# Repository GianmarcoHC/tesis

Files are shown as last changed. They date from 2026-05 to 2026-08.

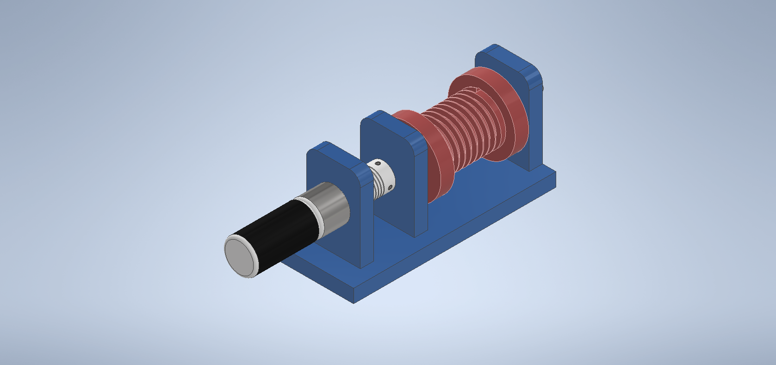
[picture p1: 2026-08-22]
cad/CAD/Ensamblaje2.png

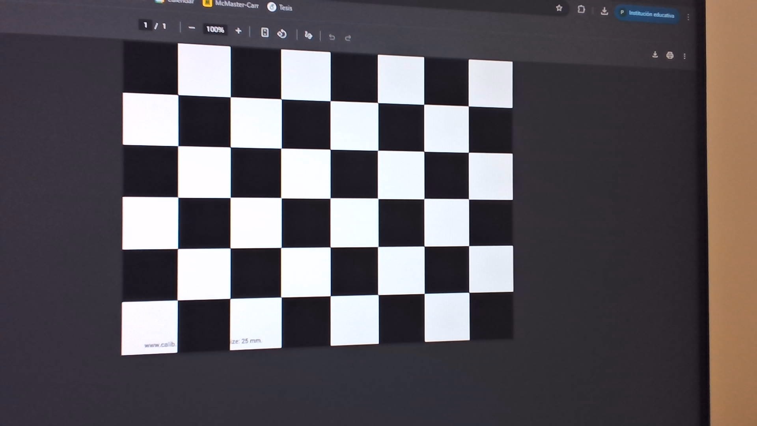
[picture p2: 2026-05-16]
camara/calib/5.jpg

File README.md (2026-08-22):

# Cable-Driven Parallel Robot (CDPR)

> Sistema de posicionamiento XYZ suspendido por cables para monitoreo y localización mediante visión artificial — Tesis UTEC

---

## ¿Qué es este proyecto?

Un **Cable-Driven Parallel Robot (CDPR)** es un robot paralelo donde los eslabones rígidos son reemplazados por cables. Este proyecto implementa un sistema de posicionamiento 3D que combina control embebido en ESP32 con visión artificial para estimar la posición y orientación del efector final en tiempo real.

El repositorio incluye tanto la implementación embebida (firmware, visión) como el modelado y análisis en MATLAB/Simulink utilizados durante el diseño y la sintonización del sistema de control.

---

## Estructura del repositorio

```
tesis/
├── cad/                    # Modelos 3D del prototipo
├── camara/                 # Visión artificial — calibración, AprilTags y pose
├── control/                # Firmware ESP32 — motores, encoders y cinemática
└── matlab/                 # Modelado, control y simulación en MATLAB/Simulink
    ├── implementacion/     # Identificación del motor, sintonización PID (AG)
    │                       # y control cinemático (cámara → Simulink → ESP32)
    └── simulacion/         # Simulación completa con Simscape Multibody
```

---

## Módulos

### `cad/`

Modelos 3D del sistema mecánico del prototipo.

**Formato:** Autodesk Inventor / STL

---

### `camara/`

Pipeline de visión artificial para localización del robot.

| Componente | Descripción |
|---|---|
| Calibración | Estimación de parámetros intrínsecos de cámara |
| AprilTags | Detección de marcadores fiduciales |
| Pose | Estimación de posición y orientación 6DOF |
| Scripts | Herramientas de prueba y validación |

**Dependencias:**
- Python 3.x
- OpenCV
- NumPy
- AprilTag

---

### `control/`

Firmware embebido para el **ESP32** desarrollado con PlatformIO + ESP-IDF.

| Componente | Descripción |
|---|---|
| Motores | Control de velocidad y dirección |
| Encoders | Lectura de posición angular |
| Cinemática | Cálculo de longitudes de cable |
| Trayectoria | Planificación y seguimiento de trayectorias |
| Comunicación | Interfaz serial con PC |

**Stack:**
- ESP32 + FreeRTOS
- ESP-IDF
- PlatformIO

> La lógica principal vive en `main/`. El sistema corre tareas concurrentes con FreeRTOS.

---

### `matlab/`

Modelado, sintonización y simulación del sistema de control, dividido en dos subcarpetas según su propósito.

#### `matlab/implementacion/`

Scripts y modelo empleados para llevar el controlador desde el diseño hasta el prototipo físico: identifican la planta real, optimizan las ganancias del PID y ejecutan el lazo de control cinemático que corre en conjunto con el prototipo.

| Componente | Descripción |
|---|---|
| Identificación del motor | Estimación de los parámetros del modelo de primer orden del motor DC (ganancia K y constante de tiempo τ) a partir de datos experimentales |
| Sintonización PID (AG) | Optimización de las ganancias Kp, Ki, Kd del lazo interno mediante algoritmo genético |
| Control cinemático (Simulink) | Modelo que recibe la posición y orientación estimadas por la cámara, calcula el error respecto a la trayectoria de referencia y genera las señales de control enviadas al ESP32 |

**Stack:** MATLAB, Simulink

#### `matlab/simulacion/`

Modelo de simulación del sistema completo, independiente del hardware, usado para validar el comportamiento dinámico del efector antes de la implementación.

| Componente | Descripción |
|---|---|
| Modelo multicuerpo | Simulación de la dinámica del efector final suspendido por cables, desarrollada con Simscape Multibody |

**Stack:** MATLAB, Simulink, Simscape Multibody

---

## Autores

**Gianmarco Humpiri Coila** — UTEC
**Piero Reyes Velarde** — UTEC

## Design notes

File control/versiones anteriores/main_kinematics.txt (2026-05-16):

#include <stdio.h>
#include "EncoderClass.h"
#include "MotorClass.h"
#include "PIDClass.h"
#include "uart_manager.h"
#include "freertos/FreeRTOS.h"
#include "freertos/task.h"
#include "esp_log.h"

// === Parámetros generales ===
const float Ts = 0.02f;  // periodo de muestreo (s)

// === UART I/O ===
static int16_t inputs[4];   // desde MATLAB → ESP32 (setpoints)
static int16_t outputs[4];  // desde ESP32 → MATLAB (posiciones)

// === PID (idéntico para todos los motores) ===
const float Kp = 1.00f;
const float Ki = 0.00f;
const float Kd = 0.00f;

// === Objetos globales ===
// Encoders
EncoderClass encoder1(GPIO_NUM_15, GPIO_NUM_2, PCNT_UNIT_0);
EncoderClass encoder2(GPIO_NUM_35, GPIO_NUM_34, PCNT_UNIT_1);
EncoderClass encoder3(GPIO_NUM_21, GPIO_NUM_22, PCNT_UNIT_2);
EncoderClass encoder4(GPIO_NUM_18,  GPIO_NUM_19,  PCNT_UNIT_3);

// Motores
MotorClass Motor1(GPIO_NUM_32, GPIO_NUM_33, MCPWM_UNIT_0, MCPWM_TIMER_0, MCPWM_OPR_A);
MotorClass Motor2(GPIO_NUM_25, GPIO_NUM_26, MCPWM_UNIT_0, MCPWM_TIMER_1, MCPWM_OPR_A);
MotorClass Motor3(GPIO_NUM_27, GPIO_NUM_14, MCPWM_UNIT_1, MCPWM_TIMER_0, MCPWM_OPR_A);
MotorClass Motor4(GPIO_NUM_5,  GPIO_NUM_4,  MCPWM_UNIT_1, MCPWM_TIMER_1, MCPWM_OPR_A);

// PID
PIDClass pid1(Kp, Ki, Kd, Ts);
PIDClass pid2(Kp, Ki, Kd, Ts);
PIDClass pid3(Kp, Ki, Kd, Ts);
PIDClass pid4(Kp, Ki, Kd, Ts);

// === Estructura de control ===
struct MotorControl {
    EncoderClass *encoder;
    MotorClass *motor;
    PIDClass *pid;
    const char *name;
    int index;   // índice para inputs/outputs
};

// === Tarea de control PID ===
void control_motor_task(void *pvParameters)
{
    MotorControl *mc = (MotorControl *)pvParameters;
    TickType_t last_wake_time = xTaskGetTickCount();

    while (true)
    {
        // Setpoint desde MATLAB (input)
        float setpoint = (float)inputs[mc->index];
        float position = mc->encoder->read_degrees();

        // Guardar posición actual en outputs → MATLAB
        outputs[mc->index] = (int16_t)position;

        // Calcular control PID
        float control = mc->pid->compute(setpoint, position);

        // Saturación de seguridad
        if (control > 100.0f) control = 100.0f;
        if (control < -100.0f) control = -100.0f;

        mc->motor->setPWM(control);

        // Log de depuración
        // ESP_LOGI(mc->name, "Set: %.1f°  Pos: %.2f°  PWM: %.2f", setpoint, position, control);

        vTaskDelayUntil(&last_wake_time, pdMS_TO_TICKS((uint32_t)(Ts * 1000.0f)));
    }
}

// === Configuración principal ===
extern "C" void app_main(void)
{
    gpio_reset_pin(GPIO_NUM_4);
    gpio_reset_pin(GPIO_NUM_14);

    // Iniciar UART (comunicación con MATLAB)
    start_uart_task(inputs, outputs);

    // Inicializar motores
    Motor1.MotorInitialize();
    Motor2.MotorInitialize();
    Motor3.MotorInitialize();
    Motor4.MotorInitialize();

    // Inicializar encoders
    encoder1.begin();
    encoder2.begin();
    encoder3.begin();
    encoder4.begin();

    vTaskDelay(pdMS_TO_TICKS(2000));

    // Crear estructuras de control
    static MotorControl mc1 = { &encoder1, &Motor1, &pid1, "MOTOR1", 0 };
    static MotorControl mc2 = { &encoder2, &Motor2, &pid2, "MOTOR2", 1 };
    static MotorControl mc3 = { &encoder3, &Motor3, &pid3, "MOTOR3", 2 };
    static MotorControl mc4 = { &encoder4, &Motor4, &pid4, "MOTOR4", 3 };

    // Crear tareas de control en core 1
    xTaskCreatePinnedToCore(control_motor_task, "control_motor1", 4096, &mc1, 5, NULL, 1);
    xTaskCreatePinnedToCore(control_motor_task, "control_motor2", 4096, &mc2, 5, NULL, 1);
    xTaskCreatePinnedToCore(control_motor_task, "control_motor3", 4096, &mc3, 5, NULL, 1);
    xTaskCreatePinnedToCore(control_motor_task, "control_motor4", 4096, &mc4, 5, NULL, 1);

    ESP_LOGI("MAIN", "Control PID + UART iniciado correctamente.");
}

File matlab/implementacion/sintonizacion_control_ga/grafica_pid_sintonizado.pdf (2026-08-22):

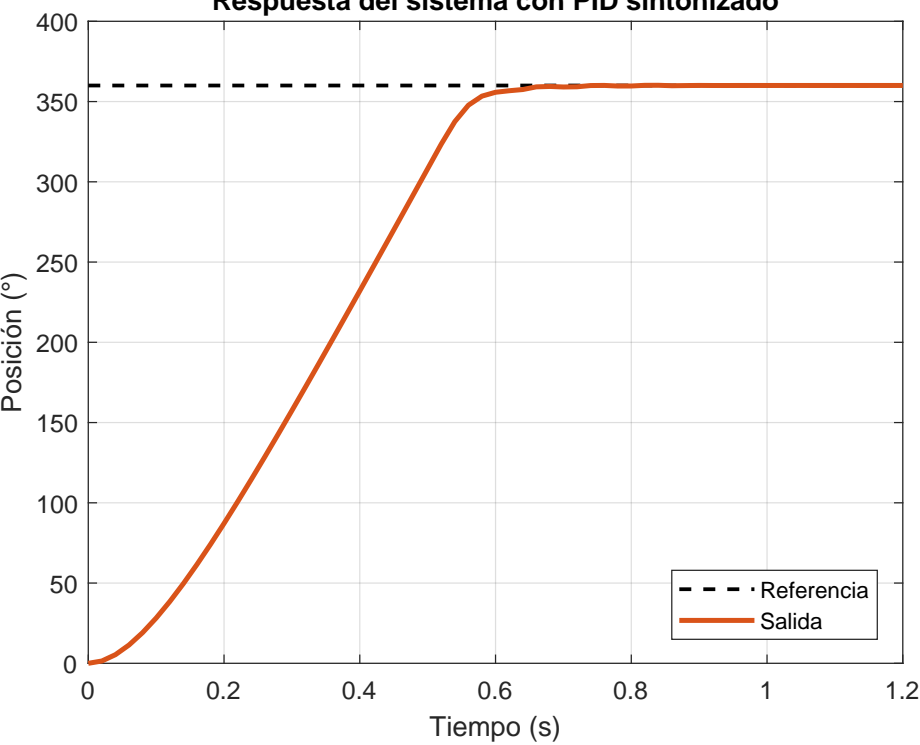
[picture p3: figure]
Tiempo (s); Posición (°); Referencia Salida

Respuesta del sistema con PID sintonizado

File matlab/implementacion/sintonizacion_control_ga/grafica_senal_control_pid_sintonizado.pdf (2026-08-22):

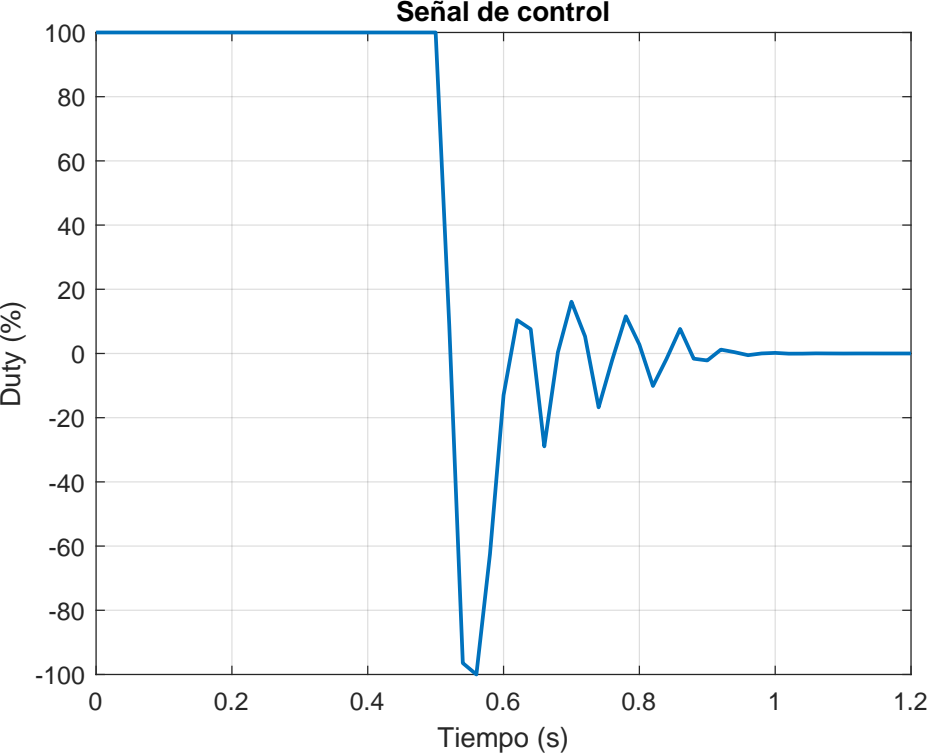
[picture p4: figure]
Tiempo (s); Duty (%); Señal de control

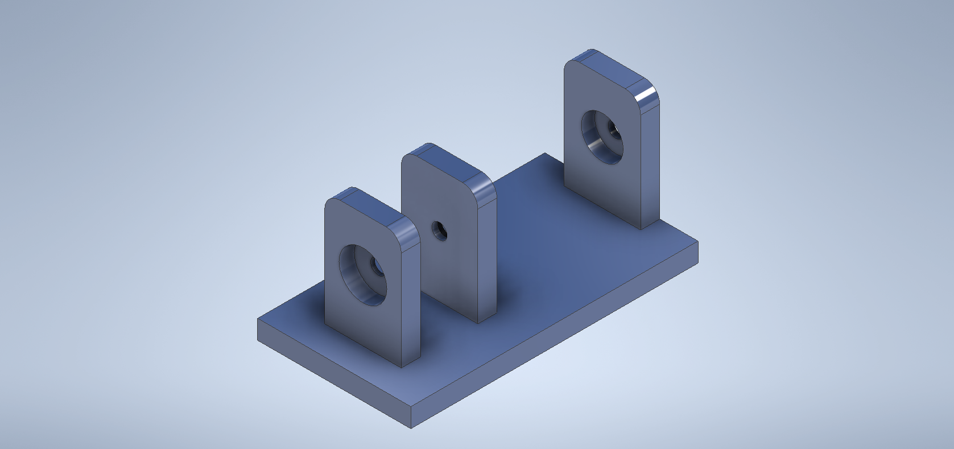
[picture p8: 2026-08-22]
cad/CAD/soporte_inferior.png

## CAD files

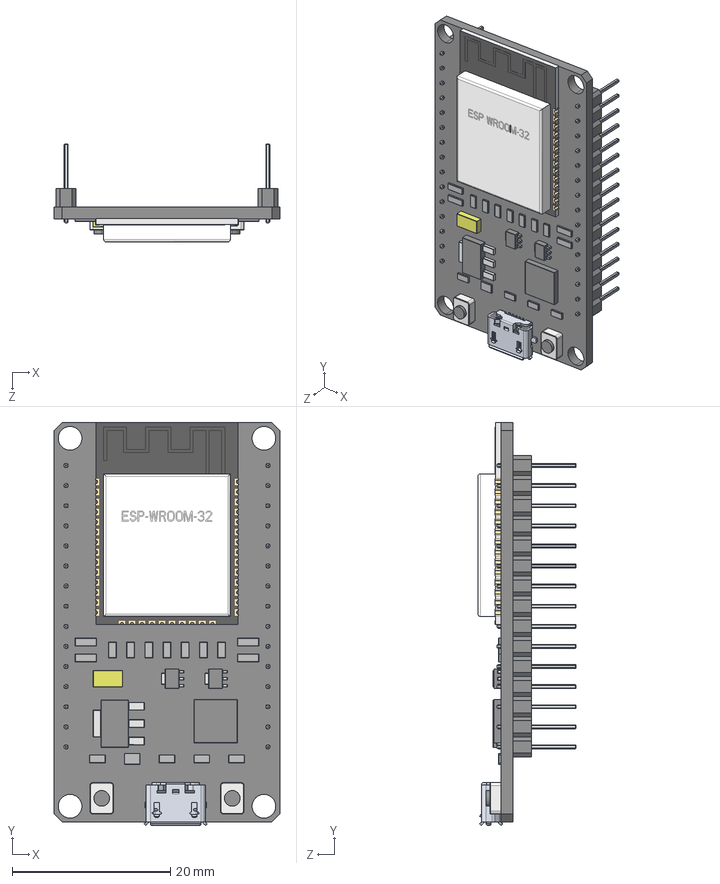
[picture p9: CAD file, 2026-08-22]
cad/CAD/Electronicos/esp-32-1.snapshot.6/ESP-32_v1.STEP
28.5 x 50.9 x 12.4 mm
6.ESP-32_Predeterminado
micro_usb_47346-0001
KiCAD-ESP-WROOM-32_Predeterminado

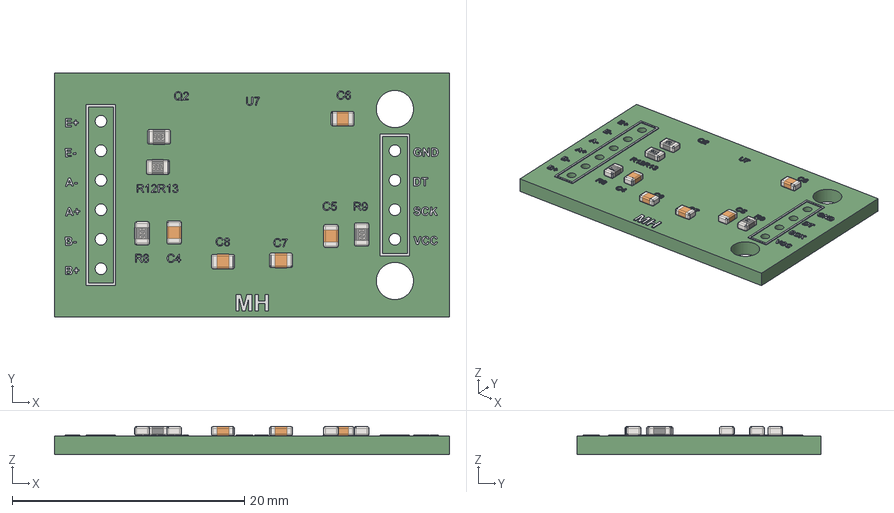
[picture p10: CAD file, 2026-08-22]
cad/CAD/Electronicos/hx711-breakout-board-1.snapshot.2/HX711 Breakout v8 ohne Pinheader.step
34.0 x 21.0 x 2.45 mm
Valor predeterminado
Valor predeterminado_1
Valor predeterminado_2 x 2
base_HX711-1
pino_HX711-1
pino_HX711-2
pino_HX711-3
pino_HX711-4
pino_HX711-5
pino_HX711-6
pino_HX711-7
pino_HX711-8
pino_HX711-9
pino_HX711-10
pino_HX711-11
pino_HX711-12
pino_HX711-13
pino_HX711-14
pino_HX711-15
pino_HX711-16
TRANSISTOR_SOT23-1
PINO_SOT23-1
PINO_SOT23-2
PINO_SOT23-3
Valor predeterminado_5 x 5

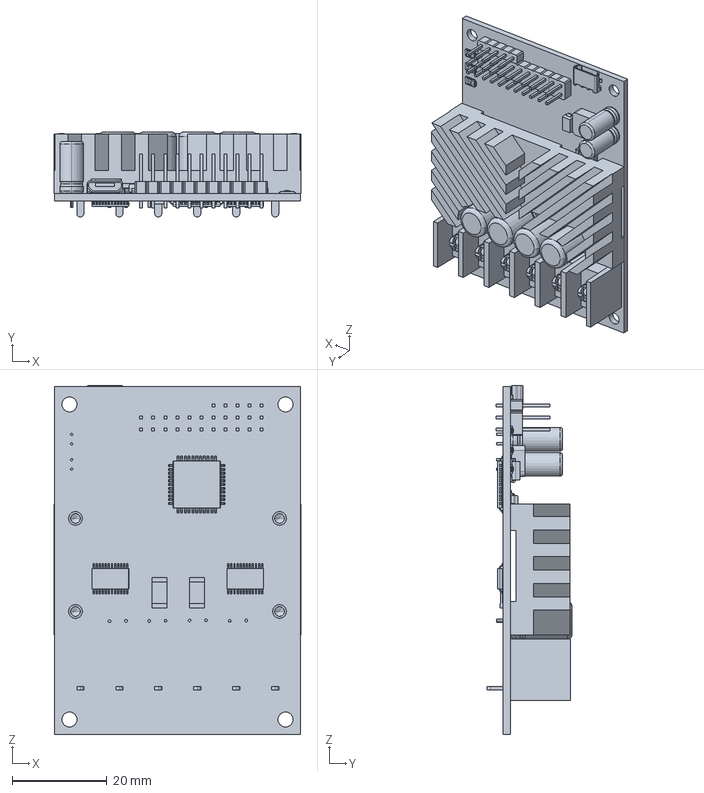
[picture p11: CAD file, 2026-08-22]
cad/CAD/Electronicos/MC15A_V5/MC15A_V5_1779569544.214.step
52.3 x 18.0 x 73.9 mm
eMachineShop.1.1
eMachineShop.1.2
eMachineShop.1.3
eMachineShop.1.4
eMachineShop.1.5
eMachineShop.1.6
eMachineShop.1.7
eMachineShop.1.8
eMachineShop.1.9
eMachineShop.1.10
eMachineShop.1.11
eMachineShop.1.12
eMachineShop.1.13
eMachineShop.1.14
eMachineShop.1.15
eMachineShop.1.16
eMachineShop.1.17
eMachineShop.1.18
eMachineShop.1.19
eMachineShop.1.20
eMachineShop.1.21
eMachineShop.1.22
eMachineShop.2.1
eMachineShop.2.2
eMachineShop.2.3
eMachineShop.2.4
eMachineShop.2.5
eMachineShop.2.6
eMachineShop.2.7
eMachineShop.2.8
eMachineShop.2.9
eMachineShop.2.10
eMachineShop.2.11
eMachineShop.2.12
eMachineShop.2.13
eMachineShop.2.14
eMachineShop.2.15
eMachineShop.2.16
eMachineShop.2.17
eMachineShop.2.18
eMachineShop.2.19
eMachineShop.2.20
eMachineShop.2.21
eMachineShop.2.22
eMachineShop.2.23
eMachineShop.2.24
eMachineShop.2.25
eMachineShop.2.26
eMachineShop.2.27
eMachineShop.2.28
eMachineShop.2.29
eMachineShop.2.30
eMachineShop.2.31
eMachineShop.2.32
eMachineShop.2.33
eMachineShop.2.34
eMachineShop.2.35
eMachineShop.2.36
eMachineShop.2.37
eMachineShop.2.38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

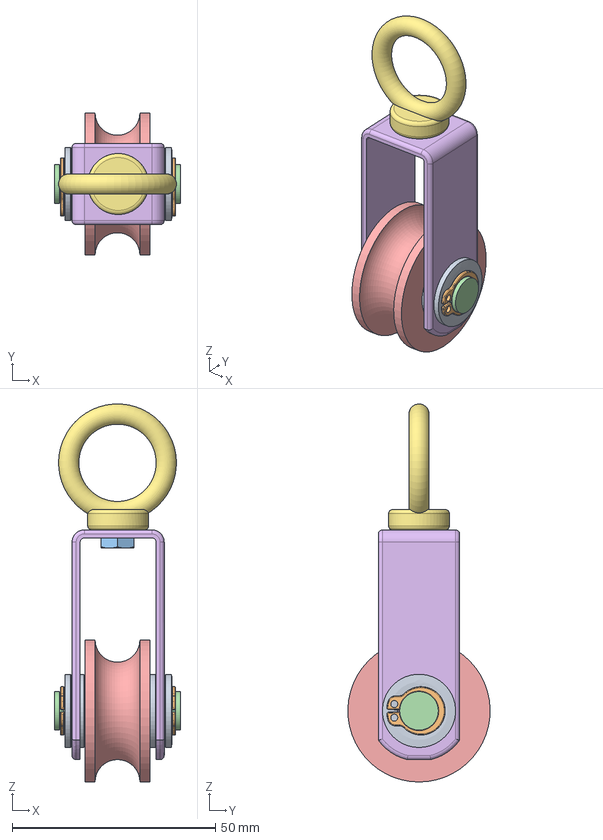
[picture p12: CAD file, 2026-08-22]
cad/CAD/Polea/suspended-pulley-1.snapshot.1/carrucola sospesa v3.step
31.0 x 35.0 x 93.0 mm
98689A117_General Purpose 18-8 Stainless Steel Washer x 4
90967A160_External Retaining Ring x 2
91287A081_18-8 Stainless Steel Hex Head Screw

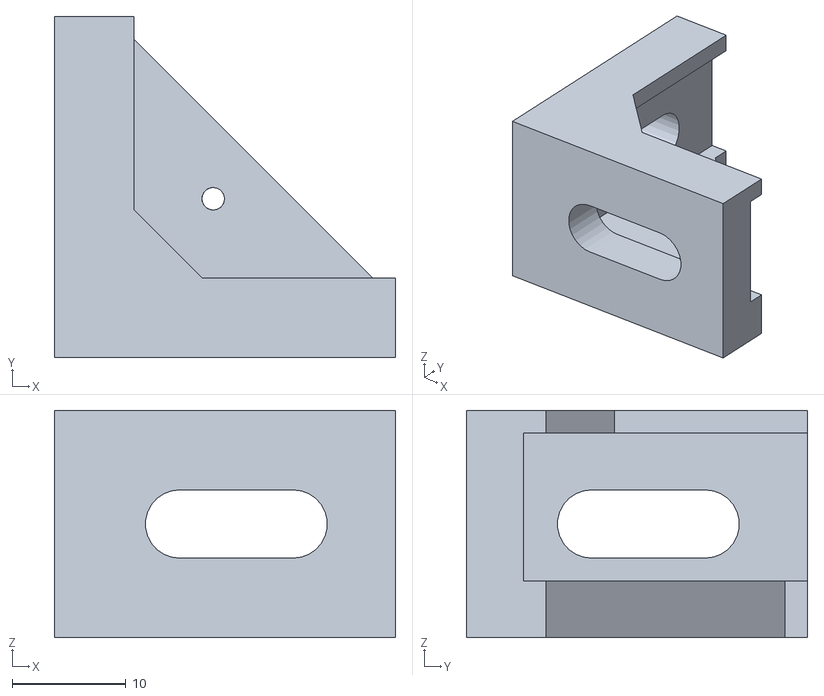
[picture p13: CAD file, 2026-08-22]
cad/Impresion 3D/soporte_gancho.stl
30.0 x 30.0 x 20.0

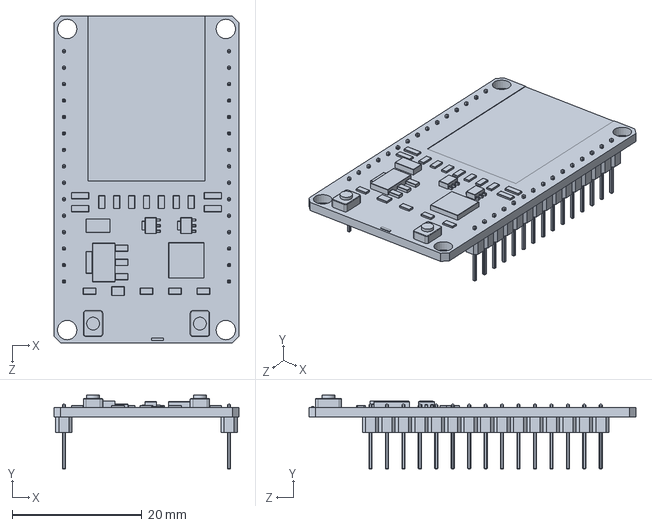
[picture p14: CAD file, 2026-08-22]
cad/CAD/Electronicos/esp-32-1.snapshot.6/6.ESP-32.SLDPRT
28.5 x 11.4 x 50.5 mm

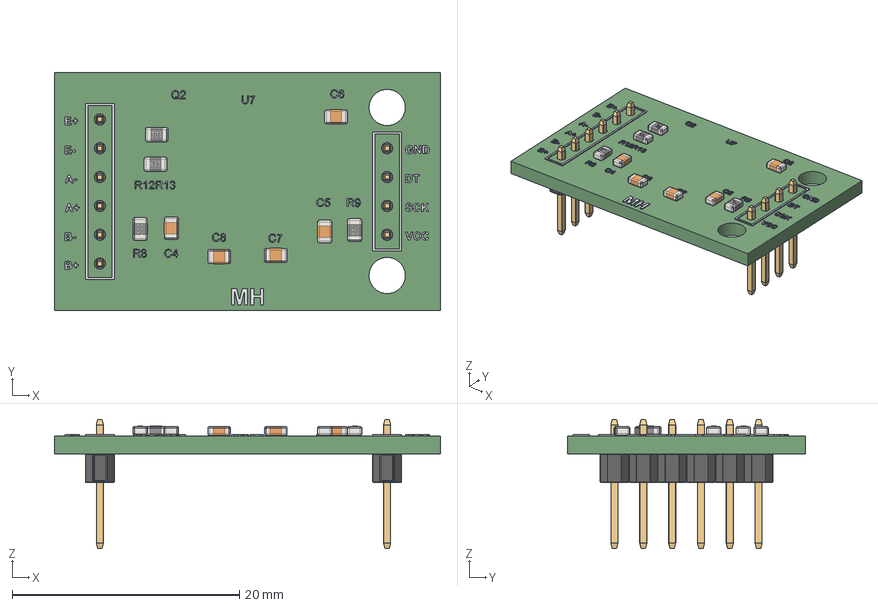
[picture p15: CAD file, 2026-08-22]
cad/CAD/Electronicos/hx711-breakout-board-1.snapshot.2/HX711 Breakout v7.step
34.0 x 21.0 x 11.4 mm
Valor predeterminado
Valor predeterminado_1
Valor predeterminado_2 x 2
base_HX711-1
pino_HX711-1
pino_HX711-2
pino_HX711-3
pino_HX711-4
pino_HX711-5
pino_HX711-6
pino_HX711-7
pino_HX711-8
pino_HX711-9
pino_HX711-10
pino_HX711-11
pino_HX711-12
pino_HX711-13
pino_HX711-14
pino_HX711-15
pino_HX711-16
TRANSISTOR_SOT23-1
PINO_SOT23-1
PINO_SOT23-2
PINO_SOT23-3
Valor predeterminado_5 x 5
Male Pin Header x 4
Male Pin Header_1 x 6

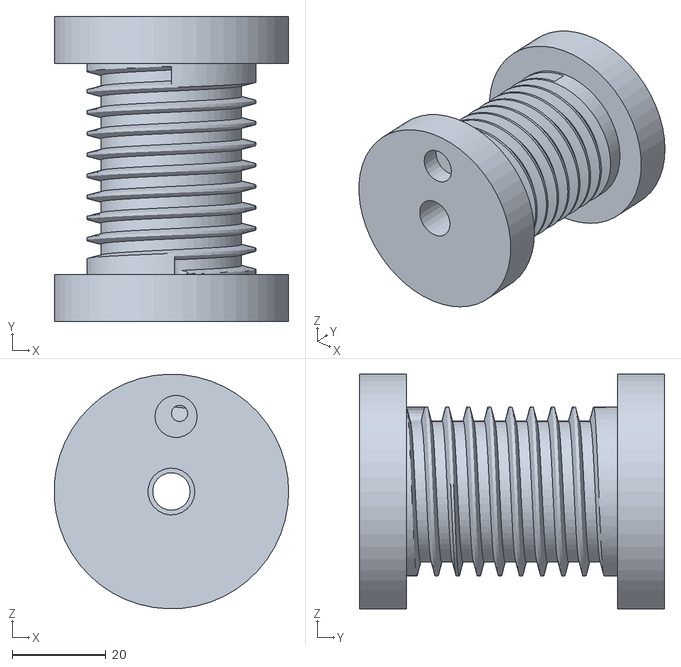
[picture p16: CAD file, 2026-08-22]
cad/Impresion 3D/carrete.stl
50.0 x 65.0 x 50.0

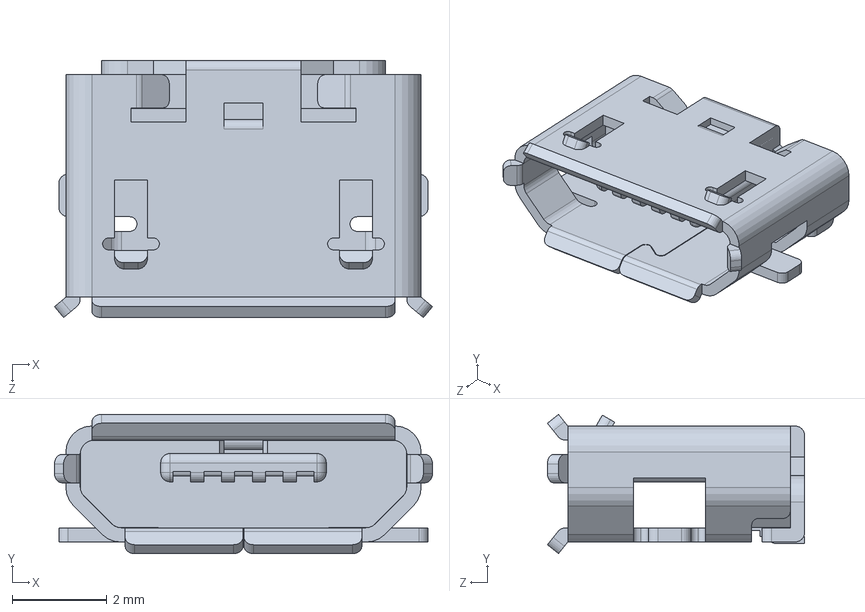
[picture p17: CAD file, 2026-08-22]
cad/CAD/Electronicos/esp-32-1.snapshot.6/micro_usb_47346-0001.SLDPRT
7.98 x 2.94 x 5.43 mm

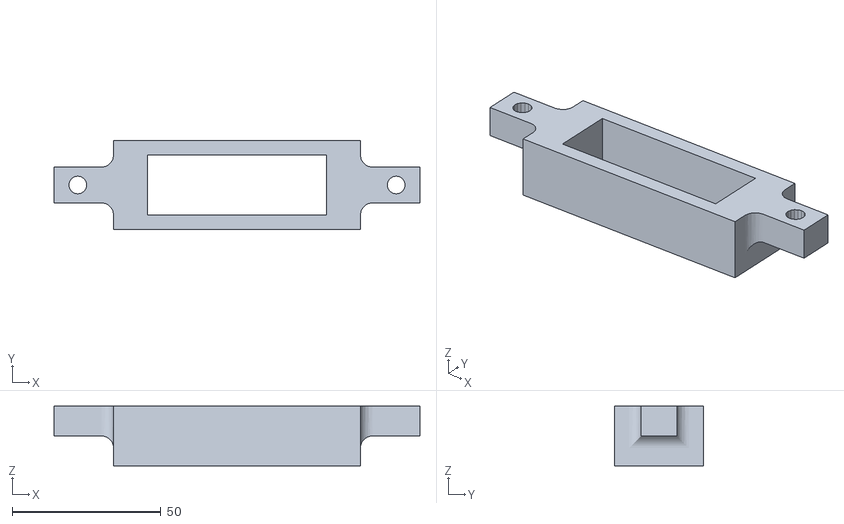
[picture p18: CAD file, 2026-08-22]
cad/Impresion 3D/carcasa_webcam.stl
123.0 x 30.0 x 20.0

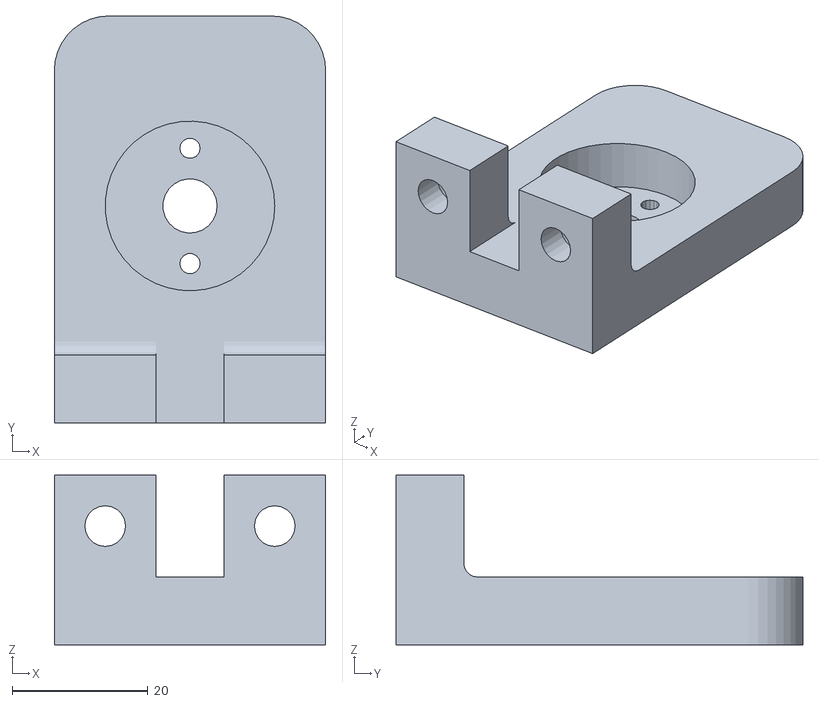
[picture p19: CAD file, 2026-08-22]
cad/Impresion 3D/sujeción motor-acople.stl
40.0 x 60.0 x 25.0

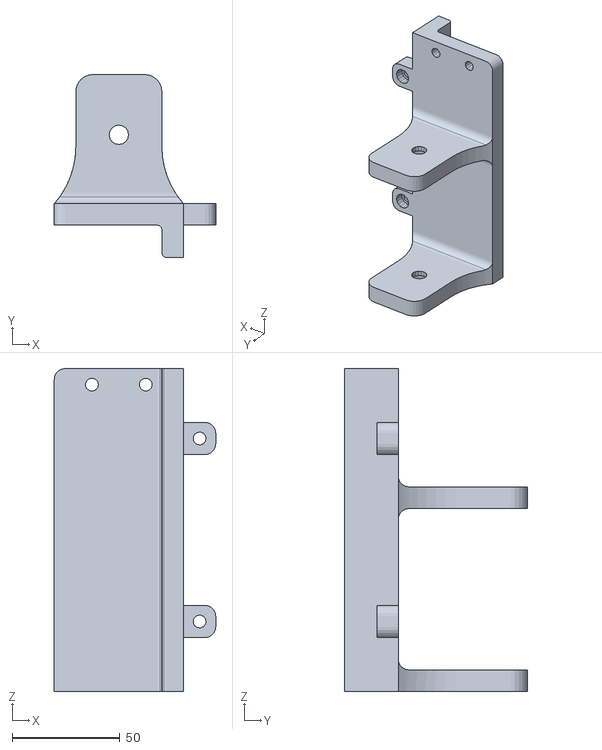
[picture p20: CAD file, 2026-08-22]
cad/Impresion 3D/soporte_inferior.stl
75.0 x 85.0 x 150.0

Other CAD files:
cad/CAD/Ensamblaje1.dwg
cad/CAD/Electronicos/MC15A_V5/MC15A_V5.IGS
cad/CAD/Electronicos/esp-32-1.snapshot.6/ESP-WROOM-32.sldprt
cad/CAD/Base.ipt
cad/CAD/BaseMotor.ipt
cad/CAD/Base_motor.ipt
cad/CAD/Brida.ipt
cad/CAD/Brida1.ipt
cad/CAD/Electronicos/MC15A_V5/MC15A_V5/311-1366-2-ND.ipt
cad/CAD/Electronicos/MC15A_V5/MC15A_V5/609-4618-1-ND.ipt
cad/CAD/Electronicos/MC15A_V5/MC15A_V5/620-1319-1-ND.ipt
cad/CAD/Electronicos/MC15A_V5/MC15A_V5/ATXMEGA32A4U-AU-ND.ipt
cad/CAD/Electronicos/MC15A_V5/MC15A_V5/CRF2512-FV-R001ELFCT-ND.ipt
cad/CAD/Electronicos/MC15A_V5/MC15A_V5/ED2949-ND.ipt
cad/CAD/Electronicos/MC15A_V5/MC15A_V5/LM22676MRE-5.0_NOPBTR-ND.ipt
cad/CAD/Electronicos/MC15A_V5/MC15A_V5/MC15A_V5.iam
cad/CAD/Electronicos/MC15A_V5/MC15A_V5/MC30A_HeatSink_V5.ipt
cad/CAD/Electronicos/MC15A_V5/MC15A_V5/MCV30A-PCB.ipt
cad/CAD/Electronicos/MC15A_V5/MC15A_V5/OldVersions/MC15A_V5.0001.iam
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

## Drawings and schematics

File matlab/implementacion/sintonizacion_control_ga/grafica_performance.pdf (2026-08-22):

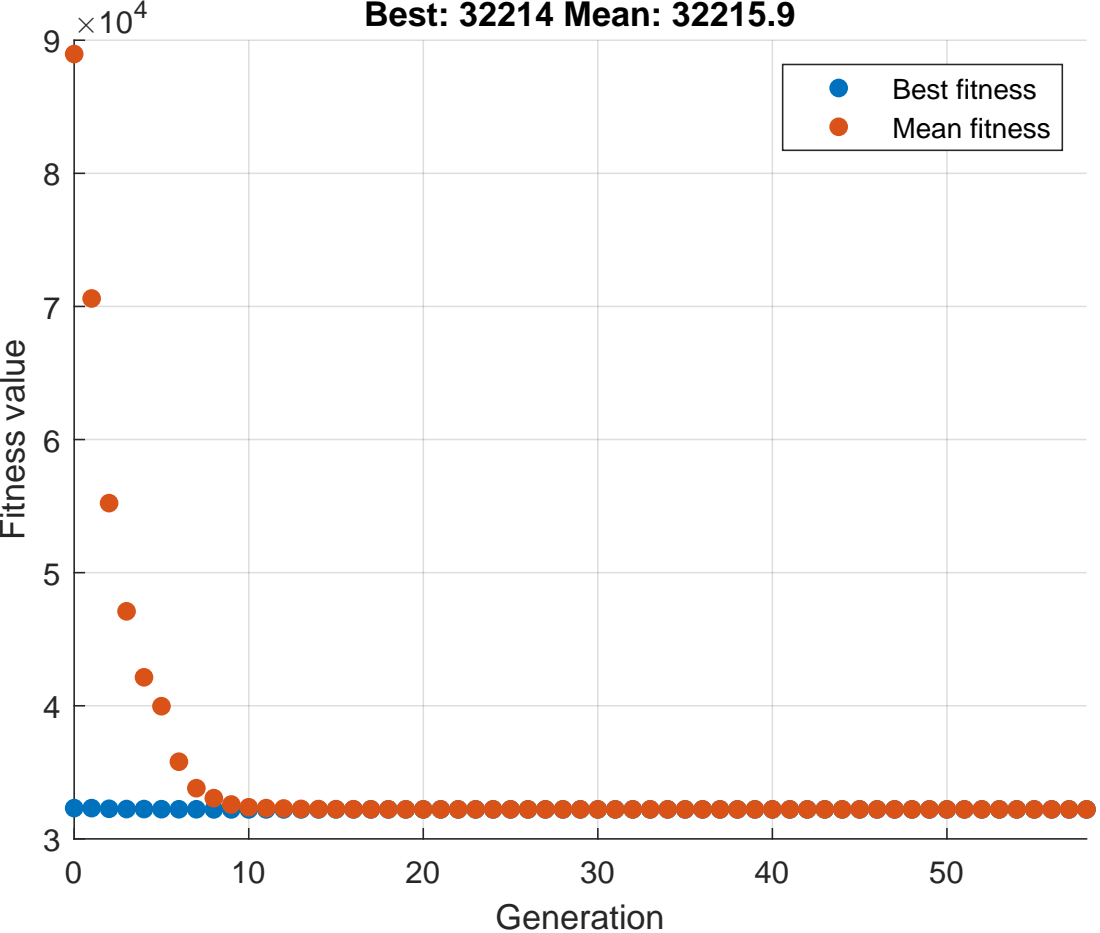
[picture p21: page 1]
Generation; Fitness value; Best: 32214 Mean: 32215.9; Best fitness Mean fitness

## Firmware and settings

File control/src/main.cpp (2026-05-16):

#include <stdio.h>
#include <string.h>

#include "freertos/FreeRTOS.h"
#include "freertos/Task.h"

#include "esp_now.h"
#include "esp_wifi.h"
#include "esp_netif.h"
#include "esp_mac.h"
#include "esp_event.h"
#include "nvs_flash.h"
#include "esp_log.h"

// ==== CONTROL (tus librerías) ====
#include "EncoderClass.h"
#include "MotorClass.h"
#include "PIDClass.h"
#include "uart_manager.h"

// ===============================
// ESP-NOW PACKET STRUCT
// ===============================
typedef struct __attribute__((packed)) {
    int16_t roll_x100;   // roll * 100
    int16_t pitch_x100;  // pitch * 100
} imu_packet_t;

static const char *TAG = "CONTROL_NODE";

// ===============================
// UART I/O
// ===============================
static int16_t inputs[4];   // MATLAB → ESP32
static int16_t outputs[4];  // ESP32 → MATLAB

// ===============================
// CONTROL DEFINITIONS
// ===============================
const float Ts = 0.02f;
static float pos_ref[4] = {0,0,0,0};

const float Kp = 1.0f;
const float Ki = 0.0f;
const float Kd = 0.0f;

// Encoders
EncoderClass encoder1(GPIO_NUM_15, GPIO_NUM_2, PCNT_UNIT_0);
EncoderClass encoder2(GPIO_NUM_35, GPIO_NUM_34, PCNT_UNIT_1);
EncoderClass encoder3(GPIO_NUM_21, GPIO_NUM_22, PCNT_UNIT_2);
EncoderClass encoder4(GPIO_NUM_18, GPIO_NUM_19, PCNT_UNIT_3);

// Motores
MotorClass Motor1(GPIO_NUM_32, GPIO_NUM_33, MCPWM_UNIT_0, MCPWM_TIMER_0, MCPWM_OPR_A);
MotorClass Motor2(GPIO_NUM_25, GPIO_NUM_26, MCPWM_UNIT_0, MCPWM_TIMER_1, MCPWM_OPR_A);
MotorClass Motor3(GPIO_NUM_27, GPIO_NUM_14, MCPWM_UNIT_1, MCPWM_TIMER_0, MCPWM_OPR_A);
MotorClass Motor4(GPIO_NUM_5,  GPIO_NUM_4,  MCPWM_UNIT_1, MCPWM_TIMER_1, MCPWM_OPR_A);

// PID
PIDClass pid1(Kp, Ki, Kd, Ts);
PIDClass pid2(Kp, Ki, Kd, Ts);
PIDClass pid3(Kp, Ki, Kd, Ts);
PIDClass pid4(Kp, Ki, Kd, Ts);

// ===============================
// ESTRUCTURA PARA EL CONTROL
// ===============================
struct MotorControl {
    EncoderClass *encoder;
    MotorClass *motor;
    PIDClass *pid;
    int index;
    const char *name;
};

// ===============================
// ESP-NOW: CALLBACK DE RECEPCIÓN
// ===============================
void espnow_recv_cb(const esp_now_recv_info_t *info, const uint8_t *data, int len)
{
    if (len == sizeof(imu_packet_t)) {
        const imu_packet_t *pkt = (const imu_packet_t*) data;

        outputs[0] = pkt->roll_x100;   // roll *100
        outputs[1] = pkt->pitch_x100;  // pitch*100
        outputs[2] = 0;
        outputs[3] = 0;

        /*
        ESP_LOGI(TAG,
                 "IMU RX: roll=%.2f  pitch=%.2f",
                 pkt->roll_x100 / 100.0f,
                 pkt->pitch_x100 / 100.0f);
        */
    }
}

// ===============================
// CONTROL DE MOTORES
// ===============================
void control_motor_task(void *pv)
{
    MotorControl *mc = (MotorControl*) pv;
    TickType_t last = xTaskGetTickCount();

    while (true)
    {
        float vel_cmd = (float)inputs[mc->index];
        pos_ref[mc->index] += vel_cmd * Ts;

        float setpoint = pos_ref[mc->index];
        float position = mc->encoder->read_degrees();

        // (SE QUITÓ) outputs[mc->index] = position;

        float control = mc->pid->compute(setpoint, position);

        if (control > 100) control = 100;
        if (control < -100) control = -100;

        mc->motor->setPWM(control);

        vTaskDelayUntil(&last, pdMS_TO_TICKS((uint32_t)(Ts * 1000)));
    }
}

// ===============================
// WI-FI + ESP-NOW INIT
// ===============================
static void wifi_init_espnow()
{
    nvs_flash_init();
    esp_netif_init();
    esp_event_loop_create_default();

    wifi_init_config_t cfg = WIFI_INIT_CONFIG_DEFAULT();
    esp_wifi_init(&cfg);

    esp_wifi_set_mode(WIFI_MODE_STA);
    esp_wifi_start();

    esp_now_init();
    esp_now_register_recv_cb(espnow_recv_cb);

    ESP_LOGI(TAG, "ESP-NOW ready");
}

// ===============================
// MAIN APP
// ===============================
extern "C" void app_main(void)
{
    gpio_reset_pin(GPIO_NUM_4);
    gpio_reset_pin(GPIO_NUM_14);


    wifi_init_espnow();

    // UART MATLAB
    start_uart_task(inputs, outputs);

    // Motores
    Motor1.MotorInitialize();
    Motor2.MotorInitialize();
    Motor3.MotorInitialize();
    Motor4.MotorInitialize();

    // Encoders
    encoder1.begin();
    encoder2.begin();
    encoder3.begin();
    encoder4.begin();

    vTaskDelay(pdMS_TO_TICKS(1000));

    static MotorControl mc1 = { &encoder1, &Motor1, &pid1, 0, "M1" };
    static MotorControl mc2 = { &encoder2, &Motor2, &pid2, 1, "M2" };
    static MotorControl mc3 = { &encoder3, &Motor3, &pid3, 2, "M3" };
    static MotorControl mc4 = { &encoder4, &Motor4, &pid4, 3, "M4" };

    // PID tasks
    xTaskCreatePinnedToCore(control_motor_task, "ctrl1", 4096, &mc1, 5, NULL, 1);
    xTaskCreatePinnedToCore(control_motor_task, "ctrl2", 4096, &mc2, 5, NULL, 1);
    xTaskCreatePinnedToCore(control_motor_task, "ctrl3", 4096, &mc3, 5, NULL, 1);
    xTaskCreatePinnedToCore(control_motor_task, "ctrl4", 4096, &mc4, 5, NULL, 1);

    ESP_LOGI(TAG, "CONTROL + ESP-NOW + UART running");
}

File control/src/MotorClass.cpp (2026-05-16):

#include "MotorClass.h"

// Constructor
MotorClass::MotorClass(gpio_num_t pwmPin, gpio_num_t dirPin,
                       mcpwm_unit_t unit, mcpwm_timer_t timer, mcpwm_operator_t op)
    : pwmPin(pwmPin), dirPin(dirPin), unit(unit), timer(timer), op(op) {}

// Inicialización MCPWM
void MotorClass::MotorInitialize() {
    // Seleccionar automáticamente el canal correcto
    mcpwm_io_signals_t signal;

    if (timer == MCPWM_TIMER_0) signal = (op == MCPWM_OPR_A) ? MCPWM0A : MCPWM0B;
    else if (timer == MCPWM_TIMER_1) signal = (op == MCPWM_OPR_A) ? MCPWM1A : MCPWM1B;
    else signal = (op == MCPWM_OPR_A) ? MCPWM2A : MCPWM2B;

    // Configurar PWM output
    mcpwm_gpio_init(unit, signal, pwmPin);

    // Configurar pin de dirección
    gpio_set_direction(dirPin, GPIO_MODE_OUTPUT);
    gpio_set_level(dirPin, 0);

    // Configurar MCPWM
    mcpwm_config_t pwm_config = {
        .frequency = 20000,           // 20 kHz
        .cmpr_a = 0,                  // duty inicial
        .cmpr_b = 0,
        .duty_mode = MCPWM_DUTY_MODE_0,
        .counter_mode = MCPWM_UP_COUNTER
    };

    mcpwm_init(unit, timer, &pwm_config);
}

// Ajustar PWM (rango -100 a +100)
void MotorClass::setPWM(float pwmValue) {
    if (pwmValue > 100.0f) pwmValue = 100.0f;
    if (pwmValue < -100.0f) pwmValue = -100.0f;

    if (pwmValue > 0.0f) {
        gpio_set_level(dirPin, 1);
        mcpwm_set_duty(unit, timer, op, 100.0 - pwmValue);
    } else {
        gpio_set_level(dirPin, 0);
        mcpwm_set_duty(unit, timer, op, - pwmValue);
    }
    // Duty Cycle
    mcpwm_set_duty_type(unit, timer, op, MCPWM_DUTY_MODE_0);
}

// Apagar motor
void MotorClass::stop() {
    mcpwm_set_duty(unit, timer, op, 0);
    mcpwm_set_duty_type(unit, timer, op, MCPWM_DUTY_MODE_0);
    gpio_set_level(dirPin, 0);
}

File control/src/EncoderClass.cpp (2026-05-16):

#include "EncoderClass.h"
#include "esp_log.h"

static const char *TAG = "ENCODER";

EncoderClass::EncoderClass(int pinA, int pinB, pcnt_unit_t unit)
    : pinA(pinA), pinB(pinB), unit(unit), count(0) {}

void EncoderClass::begin() {
    // --- Configuración del canal principal (A como pulso, B como control)
    pcnt_config_t pcnt_config = {};
    pcnt_config.pulse_gpio_num = pinA;
    pcnt_config.ctrl_gpio_num = pinB;
    pcnt_config.unit = unit;
    pcnt_config.channel = PCNT_CHANNEL_0;
    pcnt_config.pos_mode = PCNT_COUNT_INC;
    pcnt_config.neg_mode = PCNT_COUNT_DEC;
    pcnt_config.lctrl_mode = PCNT_MODE_KEEP;
    pcnt_config.hctrl_mode = PCNT_MODE_REVERSE;
    pcnt_config.counter_h_lim = 32767;
    pcnt_config.counter_l_lim = -32768;

    ESP_ERROR_CHECK(pcnt_unit_config(&pcnt_config));

    // --- Filtro antirruido (ignora pulsos < 1 µs aprox)
    pcnt_set_filter_value(unit, 100);
    pcnt_filter_enable(unit);

    // --- Inicialización del contador ---
    pcnt_counter_pause(unit);
    pcnt_counter_clear(unit);
    pcnt_counter_resume(unit);

    ESP_LOGI(TAG, "Encoder inicializado (A=%d, B=%d, UNIT=%d)", pinA, pinB, unit);
}

int16_t EncoderClass::read_raw() {
    int16_t value = 0;
    esp_err_t err = pcnt_get_counter_value(unit, &value);
    if (err != ESP_OK) {
        ESP_LOGE(TAG, "Error leyendo PCNT: %d", err);
    }
    return value;
}

float EncoderClass::read_degrees() {
    int16_t value = read_raw();
    float counts_per_rev = (float)(cpr * gear_reduction * edges_per_pulse);
    return (value * 360.0f) / counts_per_rev;
}

void EncoderClass::reset() {
    pcnt_counter_clear(unit);
}

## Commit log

2026-05-16 feat: version inicial - estructura del proyecto
    [pose_log.csv]
2026-08-22 feat: organizar carpetas y agregar cad y matlab
    [311-1366-2-ND.ipt, 6.ESP-32.SLDPRT, 6.ESP-32_Predeterminado.ipt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]
